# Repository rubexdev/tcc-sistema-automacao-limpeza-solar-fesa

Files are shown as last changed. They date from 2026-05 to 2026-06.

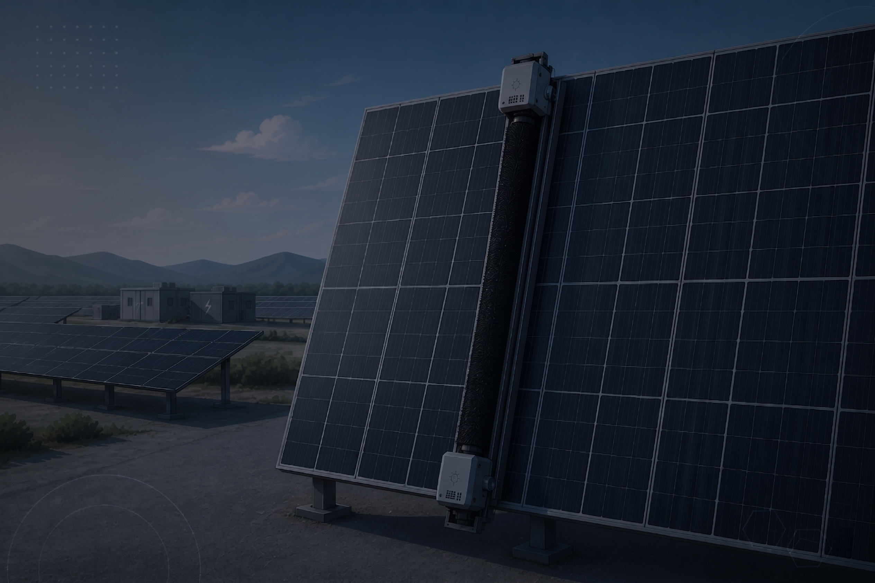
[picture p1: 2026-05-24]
interface-web/Background Interface.png

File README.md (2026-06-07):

# Protótipo de Sistema Automatizado de Limpeza de Placas Solares com Controle Web e Alimentação Autônoma

## 📝 Resumo do Projeto
Este projeto apresenta o desenvolvimento de um protótipo em escala reduzida para limpeza a seco de painéis fotovoltaicos utilizando o microcontrolador ESP32, escova cilíndrica de nylon e monitoramento remoto em tempo real via interface web integrada ao Firebase. 

O mecanismo demonstrou uma **eficiência média global de 94,0% na remoção mecânica de partículas** e validou a restauração da capacidade de geração elétrica através de ensaios comparativos de carregamento.

---

## 📺 Demonstração em Vídeo
▶️ **[Clique aqui para assistir ao vídeo de demonstração do protótipo no Google Drive](https://drive.google.com/file/d/1mZMj68gSKPB6pUv0N98ByAwMNWDLgsBo/view?usp=drive_link)**

---

## 📜 Artigo Científico Final (V-06)
📕 **[Clique aqui para ler o artigo completo em PDF](documentos/Artigo_Limpeza_Paineis_Fotovoltaicos.pdf)**

---

## ⚙️ Principais Recursos e Tecnologias
- **Hardware & Automação:** Microcontrolador ESP32 (WROOM-32), Drivers de acionamento BTS7960, Motores DC de alto torque, Sensores de Tensão e Sensores Ultrassônicos (HC-SR04).
- **Armazenamento & Nuvem:** Google Firebase (Realtime Database para sincronização em tempo real e Firebase Authentication para controle de acesso).
- **Interface Web:** Desenvolvida em HTML, CSS e JavaScript hospedada via GitHub Pages.
- **Engenharia & Modelagem:** Diagramas elétricos desenhados no EPLAN Electric P8 e modelagem mecânica 3D desenvolvida no Autodesk Inventor (conjunto modular de 23,75 kg distribuído em 8 rodas de elastômero).

---

## 📂 Estrutura do Repositório
- `/documentos`: Contém o artigo científico final do TCC em formato PDF.
- `/firmware`: Código-fonte (.ino) desenvolvido para o ESP32.
- `/interface-web`: Arquivos de código do painel de controle web (HTML/CSS/JS).
- `/eletrica`: Esquemas elétricos e diagramas gerados no EPLAN.
- `/mecanica`: Arquivos de modelagem completa (peças e conjuntos) do Autodesk Inventor.

---

## 🛠️ Análise de Engenharia (FMEA)
Foi aplicada a metodologia **FMEA (Failure Mode and Effects Analysis)** para mapear vulnerabilidades do projeto a longo prazo, definindo ações preventivas em software e hardware contra:
- Risco de microabrasões no vidro temperado por partículas rígidas externas.
- Perda de eficiência de varredura por desgaste natural das cerdas de nylon.
- Acúmulo de contaminantes aderidos (oleosidade/umidade).

---

## 🎓 Autores e Filiação Acadêmica

### Integrantes:
* Augusto Araujo Bueno
* Bruno Kayki Ribeiro de Souza
* Gustavo da Paz Coelho
* Itamar Silva de Sousa Júnior
* Rubens Melo de Souza

### Orientador:
* Me. Antônio José do Couto Pitta

### Instituição:
* Faculdade Engenheiro Salvador Arena (FESA)
* Bacharelado em Engenharia de Controle e Automação

---

## 📚 Como Citar este Trabalho (ABNT)

BUENO, A. A.; SOUZA, B. K. R.; COELHO, G. P.; SOUSA JÚNIOR, I. S.; SOUZA, R. M. **Protótipo de sistema automatizado de limpeza de placas solares com controle web e alimentação autônoma**. 2026. Artigo (Graduação em Engenharia de Controle e Automação) - Faculdade Engenheiro Salvador Arena, São Bernardo do Campo, 2026.

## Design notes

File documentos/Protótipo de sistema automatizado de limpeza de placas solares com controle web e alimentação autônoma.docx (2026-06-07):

Protótipo de sistema automatizado de limpeza de placas solares com controle web e alimentação autônoma

Augusto Araujo Bueno, Bruno Kayki Ribeiro de Souza, Gustavo da Paz Coelho, Itamar Silva de Sousa Júnior, Rubens Melo de Souza.¹

Me. Antônio José do Couto Pitta

Resumo

A eficiência de módulos fotovoltaicos é frequentemente reduzida pelo acúmulo de sujidade, exigindo limpezas periódicas para evitar perdas de geração (Araujo et al., 2019; Adekanbi, 2024). Neste contexto, este trabalho apresenta um protótipo automatizado para limpeza a seco de placas solares, com controle web e alimentação autônoma, visando otimizar a manutenção, reduzir custos e preservar a eficiência energética. A metodologia englobou o projeto mecânico no Autodesk Inventor, o elétrico no EPLAN Electric P8 e a interface web no Visual Studio Code, integrada ao Firebase. O hardware baseia-se no módulo ESP32-WROOM-32, motores DC acionados por pontes H (BTS7960), sensores de tensão e ultrassônicos, controlador de carga e escova cilíndrica de nylon. Foram realizados testes experimentais de remoção de partículas e desempenho energético. Os resultados comprovaram 94,0% de eficiência média na limpeza de sujidade simulada, garantindo operação autônoma e monitoramento remoto em tempo real. Embora os testes não tenham registrado aumento expressivo na tensão após a limpeza, o sistema validou sua viabilidade técnica, baixo impacto ambiental e forte potencial para sistemas fotovoltaicos.

Palavras-chave: Sistemas fotovoltaicos. Automação de limpeza. Controle Web. Alimentação Autônoma. Remoção de partículas.

Abstract

The efficiency of photovoltaic modules is frequently reduced by the accumulation of soiling, requiring periodic cleaning to prevent generation losses (Araujo et al., 2019; Adekanbi, 2024). In this context, this work presents an automated prototype for the dry cleaning of solar panels, with web control and autonomous power supply, aiming to optimize maintenance, reduce costs, and preserve energy efficiency. The methodology encompassed the mechanical design in Autodesk Inventor, the electrical design in EPLAN Electric P8, and the web interface in Visual Studio Code, integrated with Firebase. The hardware is based on the ESP32-WROOM-32 module, DC motors driven by H-bridges (BTS7960), voltage and ultrasonic sensors, a charge controller, and a cylindrical nylon brush. Experimental tests were conducted for particle removal and energy performance. The results proved an average efficiency of 83.5% in cleaning simulated soiling, ensuring autonomous operation and real-time remote monitoring. Although the tests did not register a significant increase in output voltage after cleaning, the system validated its technical feasibility, low environmental impact, and strong potential for photovoltaic systems.

Keywords: Photovoltaic systems. Cleaning automation. Web control. Autonomous power supply. Particle removal.

¹ Faculdade Engenheiro Salvador Arena, Centro Educacional da Fundação Salvador Arena, Estrada dos Alvarengas, 4001 - São Bernardo do Campo - SP

1 Introdução

A crescente procura por soluções sustentáveis na geração de eletricidade tem promovido mudanças significativas na matriz energética mundial. Nesse contexto, a energia solar desponta como uma alternativa estratégica, limpa e renovável, capaz de reduzir impactos ambientais e contribuir para a diversificação da matriz (Titara, 2024).

Nos últimos anos, esse movimento também se intensificou no Brasil, onde a energia solar tornou-se a segunda maior fonte elétrica do país, atrás apenas das hidrelétricas. O aumento da demanda, aliado a incentivos e ao avanço tecnológico, tem ampliado o acesso da população a essa modalidade (Costa, 2024). Em 2024, o país possuía aproximadamente 43 GW de potência instalada, e em 2025 atingiu a marca de 60 GW, passando a representar mais de 23% de toda a potência elétrica nacional (Absolar, 2025). Esse avanço trouxe impactos importantes, como a redução das emissões de CO₂, a geração de empregos e a captação de investimentos em diferentes regiões (Casarin, 2025).

No entanto a consolidação da energia solar também evidencia desafios técnicos relacionados à operação e manutenção dos sistemas instalados. A eficiência e o rendimento dos módulos fotovoltaicos estão diretamente condicionados à manutenção preventiva, em especial à limpeza das superfícies. A exposição contínua ao ambiente favorece o acúmulo de poeira, partículas provenientes da poluição atmosférica, folhas e outros resíduos, que atuam como barreiras à incidência da radiação solar sobre as células fotovoltaicas, comprometendo significativamente seu desempenho (Araujo et al., 2019). De acordo com Adekanbi (2024), “[...] as perdas anuais de energia devido ao soiling podem variar entre 3% e 5% em regiões de clima moderado, mas ultrapassam 30% em áreas áridas ou altamente poluídas.”. Esse fator assume particular relevância no Brasil, sobretudo em centros urbanos, onde o crescimento progressivo dos índices de poluição intensifica a deposição de partículas sobre os módulos e acelera a queda de eficiência (Lima; Souza, 2025).

A metodologia de limpeza convencional, predominantemente manual, apresenta limitações importantes. Entre os principais entraves destacam-se o acesso restrito a estruturas instaladas em telhados ou locais elevados, a dependência de mão de obra especializada, o custo elevado das operações periódicas e o risco de danos aos módulos quando a limpeza é realizada de forma inadequada (Mondal et al., 2018). Além disso, a realização esporádica dessas manutenções não acompanha o ritmo do acúmulo de sujeira, resultando em períodos prolongados de operação dos módulos em condições subótimas, uma vez que a presença de partículas como poeira, poluição e detritos reduz a eficiência e a capacidade de geração de energia dos sistemas fotovoltaicos (Sousa, Neto, 2024).

Diante desse cenário, a automação da limpeza se apresenta como uma alternativa promissora. A integração de microcontroladores a uma interface web supervisória possibilita o monitoramento remoto e o acionamento automático do sistema de limpeza, reduzindo a necessidade de intervenção manual e aumentando a confiabilidade da geração (Mello et al., 2003). O diferencial está na proposta de desenvolver uma solução de baixo custo com potencial de escalabilidade para diferentes tipos de empreendimentos de maior dimensão, como sistemas fotovoltaicos residenciais e usinas solares. Essa característica amplia a viabilidade da tecnologia e fortalece o papel da energia solar como componente essencial da transição energética sustentável (Lacerda; Canel; Lopes, 2022).

Nesse contexto, o objetivo geral do projeto se dá no desenvolvimento de um sistema de limpeza automatizado para placas fotovoltaicas utilizando controle web e alimentação autônoma, de modo a maximizar a eficiência energética e reduzir os custos de manutenção. Dessa forma, devem ser cumpridos os seguintes objetivos específicos:

a) Projetar a estrutura mecânica da plataforma de limpeza adequada para os módulos fotovoltaicos, garantindo cobertura completa e eficiência operacional;
b) Desenvolver alternativa elétrica para o sistema que seja alimentado pelo painel solar;
c) Desenvolver a lógica de controle do microcontrolador para a automação da limpeza e implementar a interface web supervisória para acionamento remoto e monitoramento das variáveis do sistema;
d) Projetar o mecanismo de limpeza garantindo contato tangencial com a superfície do painel fotovoltaico e livre deslizamento ao longo de seu comprimento, visando a adaptabilidade do sistema a instalações com maior quantidade de painéis;
e) Avaliar a eficiência energética dos módulos antes e depois da limpeza automatizada, visando atingir um resultado de 85% de limpeza.
2 Referencial teórico

Inicialmente, serão apresentados trabalhos acadêmicos que estudam o impacto do acúmulo de sujidade na eficiência de sistemas fotovoltaicos, bem como experiências com sistemas automatizados de limpeza de painéis e a validação de sua efetividade, fornecendo suporte conceitual e técnico para o desenvolvimento do sistema proposto.

  2.1 Impacto da sujidade sobre o desempenho de sistemas fotovoltaicos

O estudo realizado por Júnior, Cruz e Amaral (2018) analisou os efeitos do acúmulo de sujeira sobre as placas de um sistema fotovoltaico real, quantificando a redução provocada na geração de energia. Segundo Lemos et al. (2016), o impacto da sujidade pode ocasionar reduções de desempenho entre 4% e 26,3%, variando conforme o tipo de célula, as características da poeira e as condições climáticas locais. Fatores como a rugosidade da superfície dos módulos, sua inclinação, a velocidade dos ventos e a frequência de chuvas são igualmente determinantes no acúmulo de sujeira (Maghami et al., 2016; Mani; Pillai, 2010).

A sujidade é definida como o acúmulo de resíduos inorgânicos na superfície dos módulos, como poeira, pólen, carbono amorfo proveniente da queima de combustíveis e resíduos oleosos oriundos de processos produtivos e tráfego de veículos (Lemos, 2016). Como a geração elétrica depende da incidência de fótons na superfície dos módulos, qualquer barreira física reduz a absorção de energia e compromete a produção (Duarte et al., 2015). De acordo com Villalva (2015), a eficiência das células fotovoltaicas varia geralmente entre 14% e 20%, dependendo da tecnologia utilizada, tornando qualquer redução por sujidade um fator relevante para o desempenho do sistema.

Júnior, Cruz e Amaral (2018) constataram que os índices de geração decaem em média 20% em decorrência do acúmulo de sujidade, estabelecendo um intervalo mínimo de periodicidade de limpeza dos módulos. O trabalho evidenciou ainda que, em períodos de chuvas frequentes, a limpeza natural permite reduzir substancialmente ou eliminar a necessidade de limpeza manual das placas.

  2.2 Automatização da manutenção de placas solares

Sousa e Neto (2024) propõem o uso da automação como solução para reduzir custos operacionais na manutenção de módulos fotovoltaicos, destacando que o acúmulo de sujeira pode provocar perdas de até 25% na geração de energia, além de causar danos às células devido ao aquecimento desigual e à formação de fissuras.

No estudo de Vieira Júnior (apud Sousa; Neto, 2024), a coleta de dados realizada cinco meses antes e cinco meses após a limpeza dos módulos revelou um aumento de 12,08% na geração logo após a limpeza, com decréscimo progressivo de até 7,56% ao longo dos meses seguintes, confirmando a necessidade de limpezas periódicas.

Com base nesses resultados, Sousa e Neto (2024) propõem um sistema automatizado composto por sensores de sujidade, sistema de ativação automática por relés e atuadores, bomba de água e controlador (Arduino ou CLP), concluindo que a automação da manutenção representa uma estratégia eficaz para conciliar eficiência energética e viabilidade econômica.

  2.3 Sistema sustentável e automatizado para limpeza de placa solares em residências

O trabalho apresentado por Lima, Jesus e Souza (2024) descreve o desenvolvimento do projeto Clear Sun, um sistema automatizado de limpeza de placas solares voltado a residências e telhados de difícil acesso, com o objetivo de maximizar a captação de energia e reduzir custos operacionais com manutenção manual. O sistema propõe a utilização de um escovão posicionado transversalmente à placa, movimentado por um motor DC para rotação e deslocado ao longo da superfície por um motor de passo controlado por Arduino Nano e ESP32, com uso de bomba de água para a limpeza úmida — desligada automaticamente por um sensor de chuva quando umidade é detectada nas placas.

Os autores destacam que muitos usuários não realizam a limpeza necessária dos painéis, sendo que em alguns casos a higienização ocorre apenas de dois a três anos após a instalação, comprometendo significativamente a eficiência energética do sistema. Embora o projeto represente um avanço na automação da manutenção, a dependência de recursos hídricos pode ser uma limitação em regiões com escassez de água ou sem acesso fácil a reservatórios, aspecto contornado pelo sistema proposto no presente trabalho, que adota limpeza a seco.

  2.4 Limpador automático de painéis solares baseado em IoT em edifícios no Egito

Um estudo desenvolvido por Anber e Aboshosha (2024) investigou o uso de um limpador automático de painéis solares baseado em IoT no Egito, em região de clima desértico. O objetivo do trabalho foi mensurar a influência da poeira sobre os módulos fotovoltaicos e verificar a efetividade da limpeza automatizada. Os autores constataram que a eficiência dos painéis, reduzida em até 89,33% devido ao acúmulo de poeira, pôde ser restaurada para 99,4% de sua potência original por meio do sistema automatizado, demonstrando a relevância da automação na manutenção de painéis solares.

A literatura indica que a automação da limpeza, quando aliada ao monitoramento em tempo real por meio de IoT, constitui uma estratégia tecnológica eficaz para mitigar essas perdas. Nesse sentido, a figura 1 apresenta a proposta deste trabalho, que utiliza uma interface IoT, por meio de um celular, para controle de um eixo horizontal de limpeza (Anber; Aboshosha; 2024).

Os testes experimentais demonstraram que a aplicação do sistema de limpeza automática baseado em IoT foi capaz de recuperar a eficiência dos painéis para cerca de 99,5% do valor original, evidenciando a alta eficácia do método na remoção de sujeira e na restauração da capacidade de geração de energia (Anber; Aboshosha; 2024).

Figura 1 – Limpador automático de painéis solares baseado em IoT com monitoramento remoto

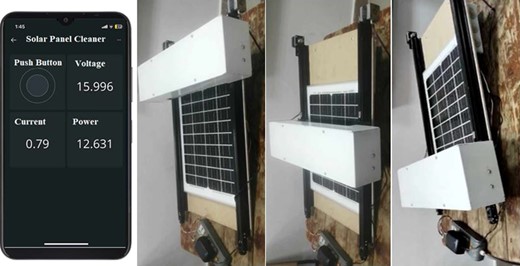
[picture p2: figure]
The proposed IoT-controlled solar panel cleaner system, (a) the dashboard app, (b) the brush at rest (home position), (c) the brush at the middle of the panel during the cleaning process, and (d) the brush at the end of the forward motion and the start to the reverse motion.

Fonte: Anber e Aboshosha (2024).

  2.5 Robô limpador de painel solar

O trabalho apresentado por Maciel et al. (2023) descreve o desenvolvimento de um robô limpador de painéis fotovoltaicos, conforme ilustrado na figura 2, com o objetivo de otimizar a eficiência na geração de energia por meio de limpeza periódica e semiautomatizada. A principal inovação do protótipo é a adoção de limpeza a seco, dispensando o uso de água ou produtos químicos, o que reduz o impacto ambiental e preserva a integridade das placas.

Figura 2 – Robô limpador para limpeza a seco de placas

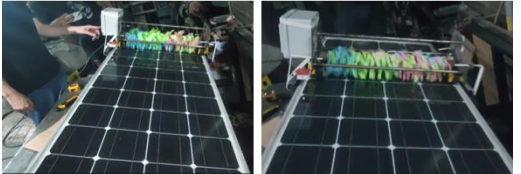
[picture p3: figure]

Fonte: Maciel et al. (2023).

O robô utiliza escovas de microfibra rotativas para remover poeira e partículas que podem reduzir em até 30% a eficiência dos módulos solares, mantendo a superfície sem riscos de danos como “hot spots”. Sua estrutura em ferro garante robustez, enquanto o controle por Arduino Uno gerencia os motores de corrente contínua e os sensores ultrassônicos, assegurando a movimentação segura e os ciclos de limpeza (Maciel et al., 2023).

Os testes de eficiência foram conduzidos com farinha de trigo como sujeira simulada, distribuída em quatro etapas de 250 g cada sobre a superfície da placa. Ao final dos ciclos de limpeza, os autores constataram uma eficiência média de 83,3% na remoção da sujeira simulada, confirmando a viabilidade prática do protótipo. A análise financeira realizada pelos autores indicou ainda que a falta de limpeza periódica pode resultar em perdas anuais significativas, reforçando o retorno econômico de soluções automatizadas de manutenção (Maciel et al., 2023).

3 Metodologia

Para o desenvolvimento do protótipo do sistema de limpeza automatizado, foram realizadas as seguintes etapas: estudo do método de limpeza, desenvolvimento dos projetos mecânico e elétrico, definição da lógica de funcionamento e programação de controle, implementação do método de comunicação entre o microcontrolador e as interfaces, desenvolvimento da interface web e da interface física local e, por fim, validação do sistema por meio de testes de funcionamento.

O protótipo é composto pelos seguintes componentes principais: um microcontrolador ESP32, três drivers de acionamento de motores BTS7960, dois motores DC de alto torque 5840-555 de 24 V, um motor DC RS555 de 12 V, dois sensores de tensão, dois sensores ultrassônicos, um display LCD 20x4 com comunicação I2C, dois botões, um controlador de carga solar, duas baterias de 12 V e uma escova de limpeza cilíndrica. O diagrama funcional, apresentado na figura 3, ilustra a arquitetura do sistema e a interação entre seus componentes.

Figura 3 – Diagrama funcional: arquitetura e interação entre subsistemas

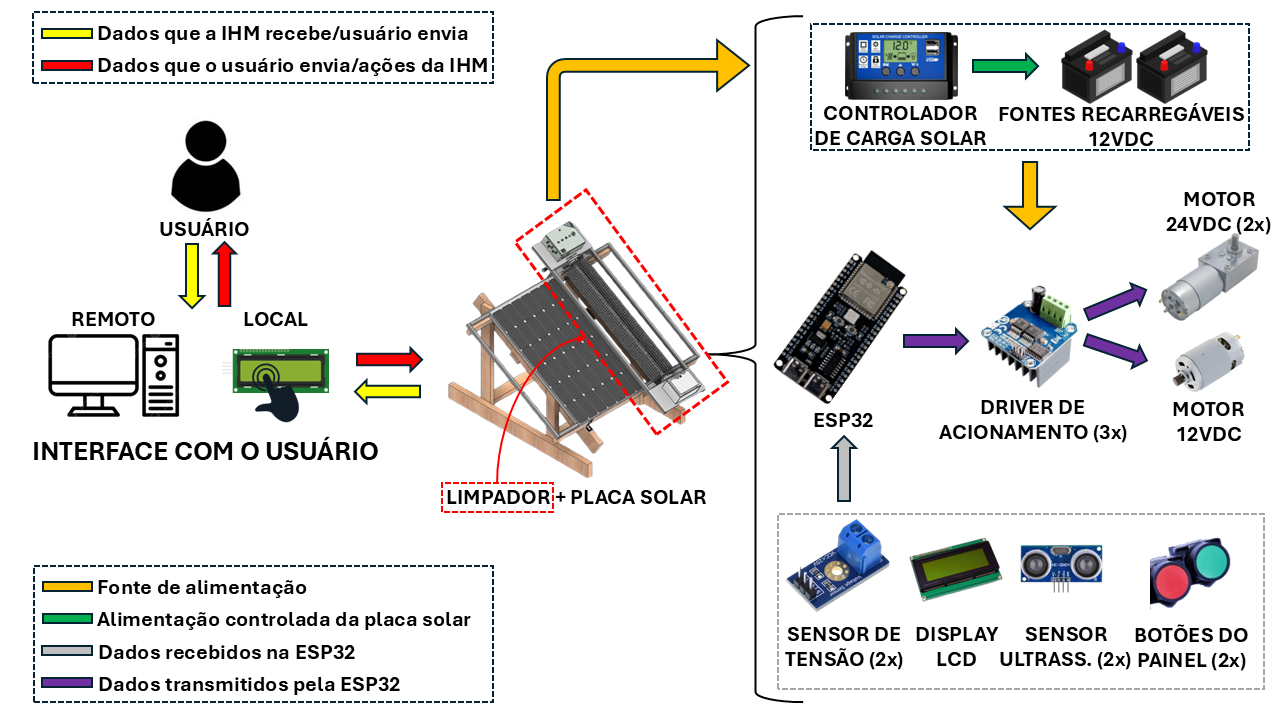
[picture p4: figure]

Fonte: Autoria Própria (2026).

Cabe destacar que o protótipo não foi desenvolvido sobre um painel fotovoltaico de dimensão padrão, uma vez que a aquisição de componentes em escala real excederia os recursos disponíveis. Optou-se, portanto, pela construção em escala reduzida, utilizando uma placa fotovoltaica com dimensões aproximadas de 1135 × 730 × 35 mm, composta por 36 células. Para a realização dos testes, foi desenvolvida uma estrutura de apoio em madeira, responsável por sustentar a placa fotovoltaica e, consequentemente, o limpador, que opera sob a superfície da placa. Essa abordagem permite demonstrar o funcionamento do sistema proposto e validar os princípios de automação aplicados ao mecanismo de limpeza.

O sistema de limpeza pode ser acionado de forma manual, por meio do painel de controle ou das interfaces desenvolvidas, ou de forma automática, mediante a definição de um intervalo de tempo para a periodicidade da limpeza. Os comandos são enviados à ESP32, responsável pelo processamento da lógica de controle e pelo acionamento dos drivers e motores. O monitoramento da posição do limpador é realizado por dois sensores ultrassônicos HC-SR04.

A alimentação do sistema é provida por duas baterias de 12 V, cuja tensão é distribuída e convertida para diferentes níveis ao longo do circuito: um conversor elevador fornece 24 V para os motores de deslocamento do limpador (modelo 5840-555), enquanto os 12 V nativos alimentam o motor da escova cilíndrica (modelo RS555) e um conversor abaixador fornece 5 V para a lógica de controle. O acionamento e reversão de todos os motores são controlados por pontes H BTS7960. As baterias são recarregadas por um controlador de carga alimentado pelo próprio painel fotovoltaico, aproveitando a energia gerada pelo sistema para sua autonomia operacional.

Para o monitoramento da alimentação do sistema, proveniente das baterias, utilizam-se dois sensores de tensão, cujos dados são enviados à ESP32, permitindo uma análise indireta do desempenho do painel fotovoltaico.

  3.1 Método de limpeza e material da escova

Com base nos referenciais teóricos estudados, o método adotado pelo sistema de limpeza automatizado desenvolvido é a limpeza a seco, realizada por meio de um eixo rotativo acoplado a uma escova cilíndrica que percorre a superfície do painel por contato mecânico, conforme ilustrado na figura 4. O princípio de funcionamento consiste na rotação da escova em alta velocidade, promovendo a remoção de partículas depositadas sobre a superfície por meio de contato mecânico controlado. A geometria cilíndrica permite uma distribuição uniforme das forças de contato ao longo da área de limpeza, garantindo maior eficiência na remoção da sujeira sem concentrar esforços excessivos em pontos específicos.

Figura 4 – Método de limpeza a seco proposto para o sistema de limpeza automatizado

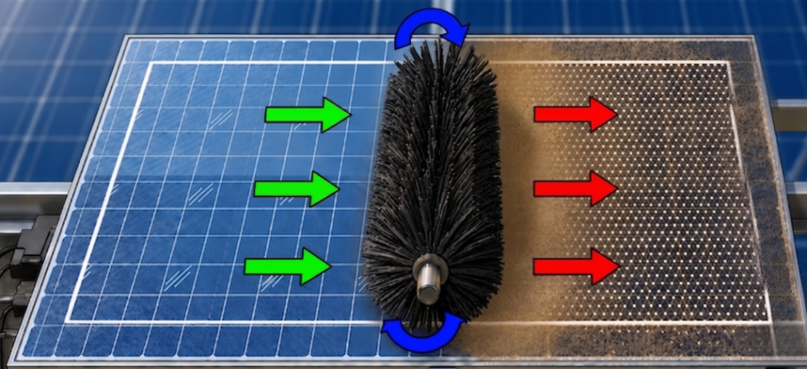
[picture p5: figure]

Fonte: Autoria Própria (2026).

A adoção do sistema de limpeza a seco justifica-se por aspectos técnicos, ambientais e operacionais. Esse método elimina o consumo hídrico, fator crucial para regiões que enfrentam escassez de água. Além disso, evita a formação de resíduos minerais provenientes da evaporação, os quais podem comprometer o desempenho dos módulos. Outro benefício relevante é a mitigação de riscos elétricos durante a operação, pois a ausência de água dispensa a necessidade de desligamento do sistema, garantindo maior continuidade na geração de energia. Por fim, a eliminação de componentes hidráulicos simplifica a estrutura do sistema, reduzindo os custos operacionais e facilitando sua aplicação em ambientes remotos e com soluções automatizadas.

Tomando como referência o painel fotovoltaico de 36 células, o dimensionamento da escova foi realizado por meio de projeto sob medida no software Autodesk Inventor, resultando nas seguintes especificações: diâmetro externo de 200 mm, comprimento de 1100 mm, furo central de 25 mm para acoplamento ao eixo e base estrutural de 75 mm, com cerdas de nylon preto com espessura entre 0,20 mm e 0,30 mm, conforme ilustrado na figura 5(a). A figura 5(b) apresenta a escova fabricada conforme o projeto, composta por cerdas de nylon preto e reforçada para uso contínuo.

Figura 5 – Vista isométrica da escova em 3D 5(a) e perspectiva frontal da escova fabricada 5(b)

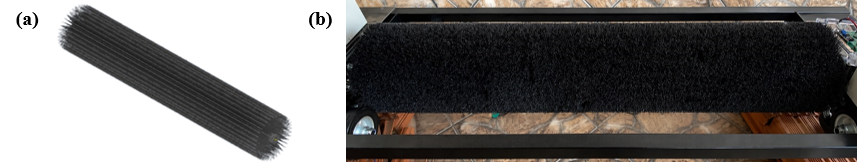
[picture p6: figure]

Fonte: Autoria Própria (2026).

A escolha do nylon como material das cerdas contribui para a preservação da integridade do vidro do módulo fotovoltaico, uma vez que apresenta dureza inferior à do vidro, reduzindo o risco de microabrasões. Esse fator é fundamental para manter a eficiência energética do sistema ao longo do tempo, evitando perdas associadas a danos superficiais.

Dessa forma, o método de limpeza adotado estabelece as bases para o desenvolvimento estrutural do sistema uma vez que as características geométricas e operacionais da escova influenciam diretamente na concepção mecânica do conjunto. Assim, torna-se necessária a modelagem do limpador horizontal, considerando aspectos como dimensões, distribuição de massa, pontos de fixação e integração dos componentes responsáveis pelo deslocamento e acionamento do sistema.

  3.2 Modelagem mecânica

Após a definição do método de limpeza e do material da escova, o projeto mecânico foi modelado no software Autodesk Inventor com base nos componentes adquiridos para o protótipo. Foram definidos os principais elementos estruturais do limpador, como suportes de fixação, eixo de movimento, base dos motores e proteções, sendo cada peça modelada individualmente e posteriormente integrados ao conjunto. A figura 6(a) apresenta a vista explodida do projeto mecânico em 3D, enquanto a figura 6(b) mostra a lista de componentes e suas respectivas massas, resultando em um peso total aproximado do conjunto de 23,75 kg.

Figura 6 – Montagem em 3D completa 6(a) e lista de peças 6(b)

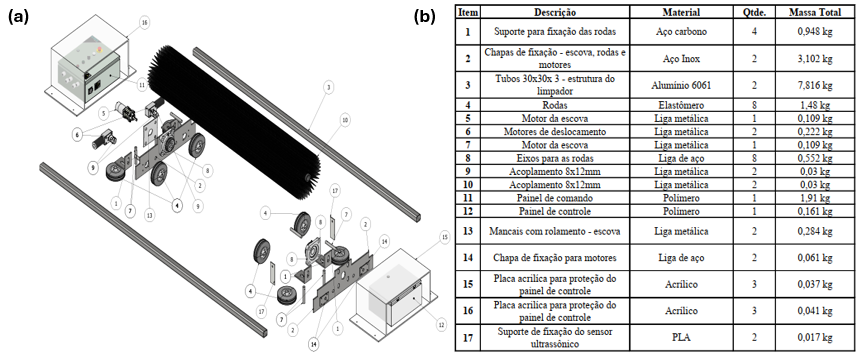
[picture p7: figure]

Fonte: Autoria Própria (2026).

A estrutura do limpador é composta por perfis de alumínio e chapas de aço soldadas, que integram os suportes das rodas, a base dos motores e o alojamento dos painéis de comando, formando um conjunto rígido e funcional. A Figura 7(a) apresenta a vista isométrica do projeto tridimensional, enquanto a Figura 7(b) ilustra o limpador horizontal construído.

Figura 7 – Vista isométrica em 3D 7(a) e perspectiva frontal do protótipo montado 7(b)

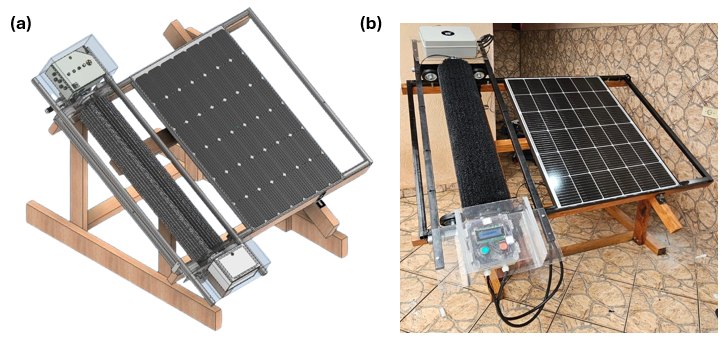
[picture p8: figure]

Fonte: Autoria Própria (2026).

O projeto foi concebido com base no princípio da modularidade: o limpador é sobreposto ao painel fotovoltaico, sem fixação permanente, permitindo sua remoção e reinstalação em outros conjuntos de placas, o que amplia a aplicabilidade do sistema e reduz custos de implantação. Essa concepção modular, aliada às características geométricas e à massa total do conjunto, determinou as demandas operacionais envolvidas no deslocamento e acionamento do sistema, influenciando diretamente o dimensionamento elétrico e a arquitetura do sistema de controle.

Dessa forma, faz-se necessário o desenvolvimento de um painel elétrico capaz de integrar os motores, sensores e dispositivos de proteção, garantindo o funcionamento seguro e automatizado do sistema.

  3.3 Circuito elétrico

O projeto elétrico foi desenvolvido no software EPLAN Electric P8, ferramenta de engenharia que facilita a visualização das ligações e a montagem do circuito. O diagrama elétrico pode ser observado na figura 8.

Figura 8 – Diagrama elétrico do projeto

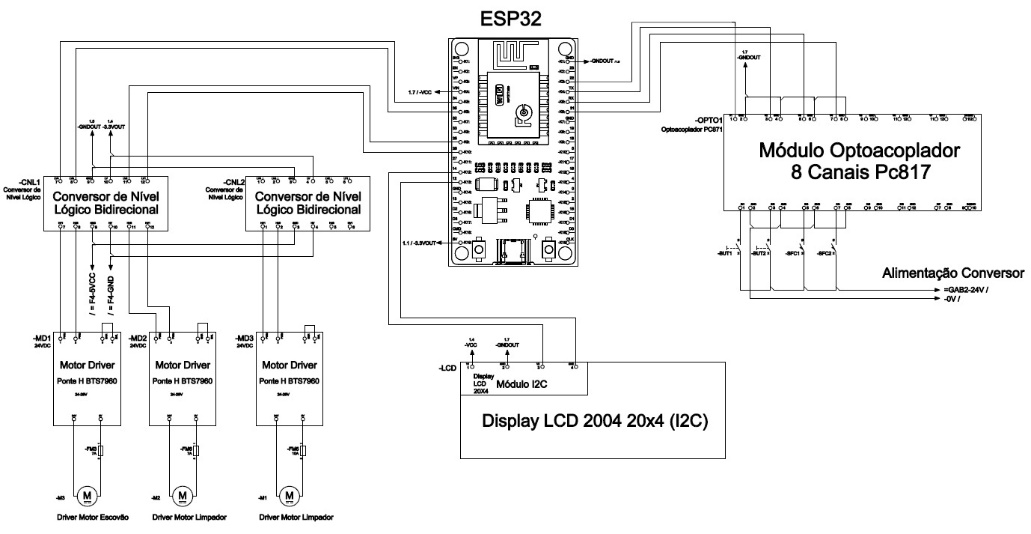
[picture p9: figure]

Fonte: Autoria Própria (2026).

Dado que o sistema integra componentes de acionamento de alta tensão e componentes de controle mais sensíveis, optou-se pela separação em dois painéis distintos: o painel de comando, destinado aos componentes de acionamento e maior tensão, e o painel de controle, de menor porte, responsável por abrigar os componentes eletrônicos mais sensíveis.

O painel de comando, apresentado na figura 9, abriga os seguintes componentes: controlador de carga solar (A), responsável pela gestão de corrente e tensão do circuito; disjuntor bipolar (B), para proteção exclusiva do controlador de carga; conversor elevador de tensão (C), responsável pela conversão de 12 V para 24 V; e três drivers BTS7960 (D), sendo dois destinados aos motores de deslocamento e um ao motor de rotação da escova. O painel conta ainda com prensas-cabo (E), para entrada e saída de cabos, e uma ventoinha (F), para dissipação do calor gerado pelos componentes em operação.

Figura 9 – Vista interna dos componentes do Painel de Controle.

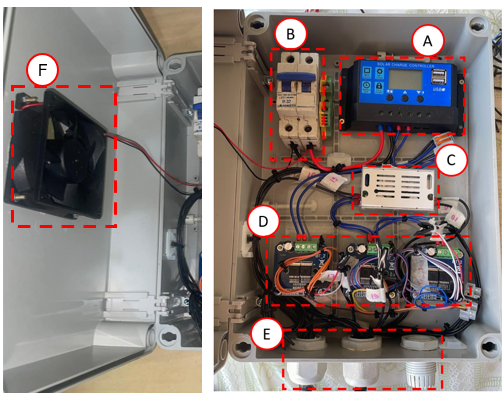
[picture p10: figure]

Fonte: Autoria Própria (2026).

O painel de controle, apresentado nas Figuras 10(a) e 10(b), abriga os seguintes componentes: controlador ESP32 (A), microcontrolador central responsável pela lógica e controle do sistema; módulo optoacoplador de 8 canais (B), utilizado para leitura dos botões de 24 V, protegendo a ESP32 contra sinais de tensão incompatíveis; conversores de nível bidirecional (C) e sensores de tensão (D), soldados em placa de soldagem, sendo os primeiros responsáveis pela elevação do sinal de 3,3 V para 5 V para acionamento das pontes H, e os segundos pelo monitoramento da tensão das baterias; conversor abaixador de tensão (E), que converte 24 V para 5 V para alimentação da lógica de controle; display LCD (F), utilizado como interface visual local; botões de 24 V verde (G) e vermelho (H), para acionamentos manuais e interação com o display; e prensas-cabo (I), para entrada e saída de cabos.

Figura 10 – Disposição interna do painel de controle 10(a) e disposição externa do painel de controle 10(b).

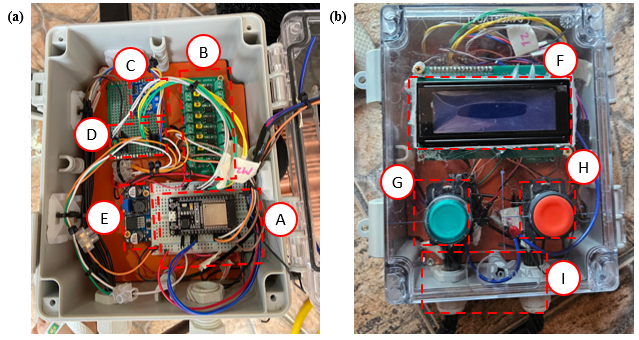
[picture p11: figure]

Fonte: Autoria Própria (2026).

A alimentação do sistema ocorre por meio de duas baterias de 12 V, mantidas carregadas por um ciclo de autonomia energética provido pela própria placa fotovoltaica do protótipo, conforme ilustrado na figura 11. O ciclo se inicia com a geração de energia pelo painel fotovoltaico, que fornece tensão de aproximadamente 24 V e corrente nominal de até 7,55 A. Essa energia é gerida pelo controlador de carga solar, responsável por regular a tensão e a corrente de entrada, garantindo o carregamento seguro das baterias. Uma vez carregadas, as baterias fornecem alimentação ao sistema de controle e acionamento, que por sua vez comanda o limpador durante os ciclos de limpeza. Concluída a operação, o sistema retorna ao estado de monitoramento, aguardando o próximo ciclo programado, enquanto o painel fotovoltaico continua recarregando as baterias.

Figura 11 – Ciclo da alimentação autônoma do protótipo.

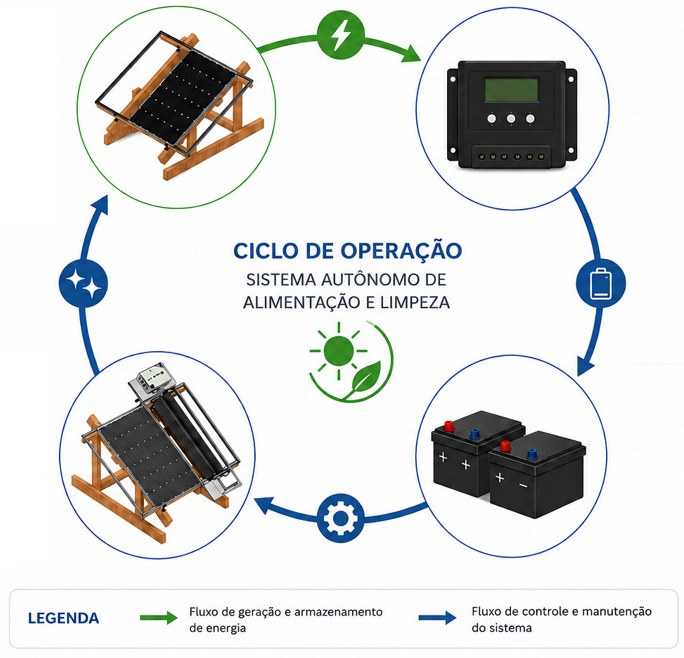
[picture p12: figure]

Fonte: Autoria Própria (2026).

  3.4 Lógica de funcionamento

O sistema de limpeza foi concebido com base em uma estratégia de operação por intervalos de tempo configuráveis pelo usuário. Nessa abordagem, o operador define os períodos ao longo do dia em que a limpeza deve ser executada, e o sistema realiza automaticamente dois ciclos completos a cada intervalo programado. Cada ciclo consiste em uma passagem de ida e uma passagem de volta do limpador ao longo da superfície do painel fotovoltaico. A repetição consecutiva das passagens tem por objetivo maximizar a remoção de partículas e resíduos, compensando a ausência de um sensor de feedback que ateste diretamente o grau de limpeza atingido.

A execução de cada ciclo é controlada pelo acionamento coordenado dos três motores DC e monitorada pelos sensores ultrassônicos dispostos nas extremidades do percurso. A atuação sequencial desses sensores indica a conclusão de cada passagem, comandando a inversão do movimento ou a interrupção do ciclo conforme a etapa em execução. A sequência lógica completa desse processo é ilustrada pelo fluxograma da figura 12.

Figura 12 – Fluxograma do processo

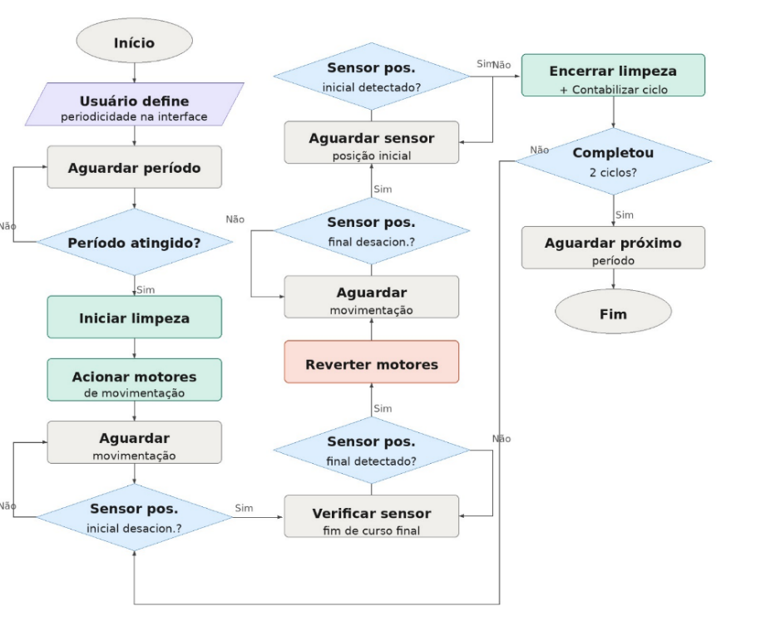
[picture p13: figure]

Fonte: Autoria Própria (2026).

Além do modo automático descrito e apresentado no fluxograma, o sistema oferece um modo manual de operação, no qual o usuário pode acionar a limpeza a qualquer momento por meio da interface web ou da interface física local, independentemente dos intervalos programados. Essa dualidade de controle busca garantir flexibilidade operacional e assegura a continuidade do funcionamento mesmo em situações em que o agendamento automático não seja suficiente ou adequado.

O firmware do sistema foi desenvolvido no Arduino IDE com o framework Arduino para ESP32. A escolha da ESP se justifica pela conectividade Wi-Fi nativa, que viabiliza a integração com serviços em nuvem e o controle remoto dos periféricos, aspectos fundamentais para a proposta de controle web adotada no projeto.

  3.5 Comunicação

Como solução de comunicação entre o microcontrolador e as interfaces de controle, foi adotado o Firebase, plataforma de desenvolvimento em nuvem oferecida pela Google. A plataforma oferece três recursos que potencializam o projeto: (i) hospedagem de dados em nuvem sem necessidade de servidor próprio, de modo que qualquer dispositivo conectado à internet acessa os dados da ESP32 diretamente; (ii) sincronização em tempo real por meio do Realtime Database, um banco de dados NoSQL que atualiza simultaneamente todos os clientes conectados, aspecto especialmente relevante dado que o sistema conta com interface web e interface física operando em paralelo; e (iii) o Firebase Authentication, que restringe o acesso às informações apenas a usuários previamente cadastrados na plataforma.

No banco de dados, todas as variáveis de monitoramento e controle remoto estão organizadas em um único nó estruturado, contemplando: comandos manuais, modo de operação (manual/automático), status dos motores e sentido de rotação (inferido pelo acionamento dos bits da ponte H), status de comunicação com a ESP32, periodicidade configurada para os ciclos de limpeza, contagem de ciclos realizados e tensão individual das duas baterias. Cada variável possui valores predefinidos na estrutura do banco, tratados e selecionados internamente pela programação da ESP32, conforme ilustrado na figura 13.

Figura 13 – Variáveis de tratativa remota no Firebase

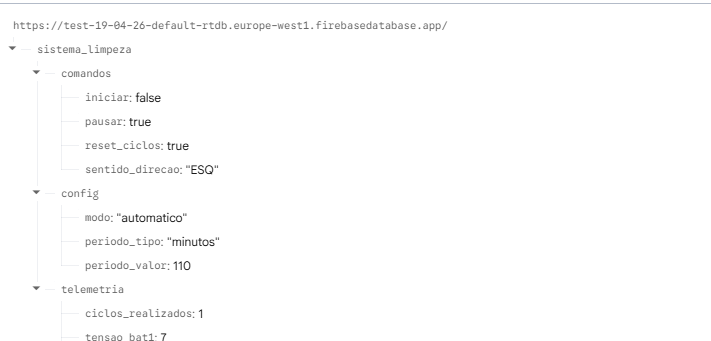
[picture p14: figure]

Fonte: Autoria Própria (2026).

A comunicação entre a ESP32, o Firebase e a Interface Web são estabelecidos por meio de três chaves de configuração únicas por projeto: o apiKey, que identifica a aplicação na plataforma; o authDomain, responsável pelo gerenciamento do fluxo de autenticação; e a databaseURL, que aponta para o banco de dados onde estão armazenadas todas as variáveis do sistema.

  3.6 Interface web

A interface web tem como objetivo permitir o monitoramento e controle remoto do sistema por qualquer dispositivo conectado à internet. Foi desenvolvida em HTML, CSS e JavaScript no Visual Studio Code, com hospedagem no GitHub Pages, o qual disponibiliza o sistema por meio de um link de acesso público com integração direta ao Firebase.

A versão final é composta por duas telas principais. A primeira corresponde ao login, apresentada na figura 14, que restringe o acesso a usuários cadastrados no Firebase Authentication e exibe o status de conexão da ESP32. Após a autenticação, o usuário é direcionado à tela operacional, detalhada na figura 15.

Figura 14 – Tela inicial da interface web

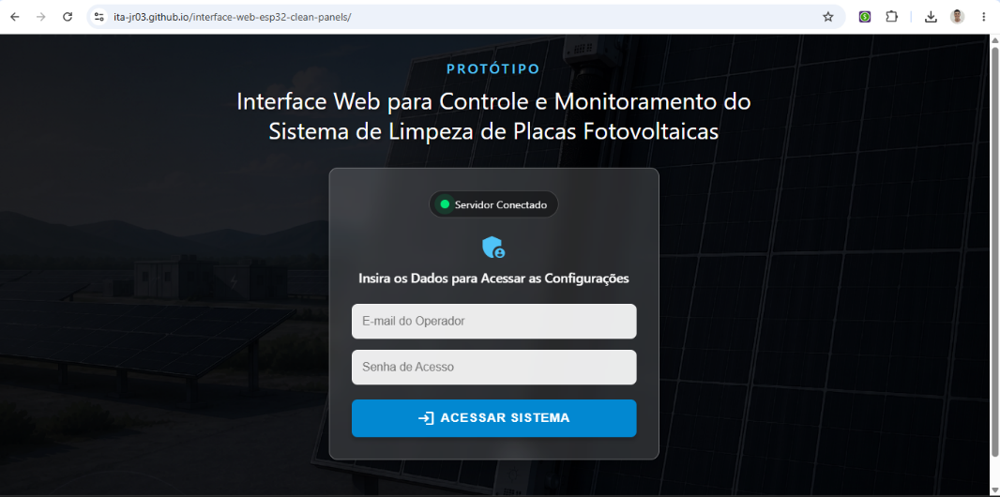
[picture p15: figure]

Fonte: Autoria Própria (2026).

Figura 15 – Tela operacional da interface web

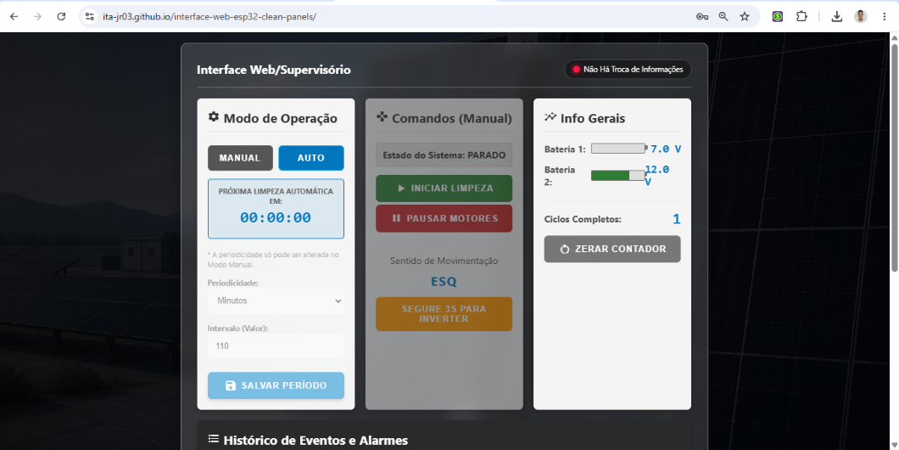
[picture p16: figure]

Fonte: Autoria Própria (2026).

A tela operacional atua como o ambiente principal da interface, funcionando como um sistema supervisório completo. A partir dela, o operador pode alternar entre os modos de operação (manual e automático), enviar comandos de acionamento (restritos ao modo manual) e ajustar a periodicidade das rotinas, definindo a unidade de tempo (minutos, horas ou dias) e o valor numérico do período. A interface também exibe dados gerais de telemetria, como a tensão das baterias de alimentação do circuito e a contagem de ciclos realizados.

Por fim, o sistema conta com uma aba dedicada ao diagnóstico e segurança da aplicação, conforme ilustra a figura 16. Nesta área, o usuário pode visualizar o histórico de alarmes e eventos do sistema, além de realizar o cadastro de novos operadores, com atualização e validação direta no banco de dados do Firebase.

Figura 16 – Histórico de alarmes, eventos e cadastro de usuários

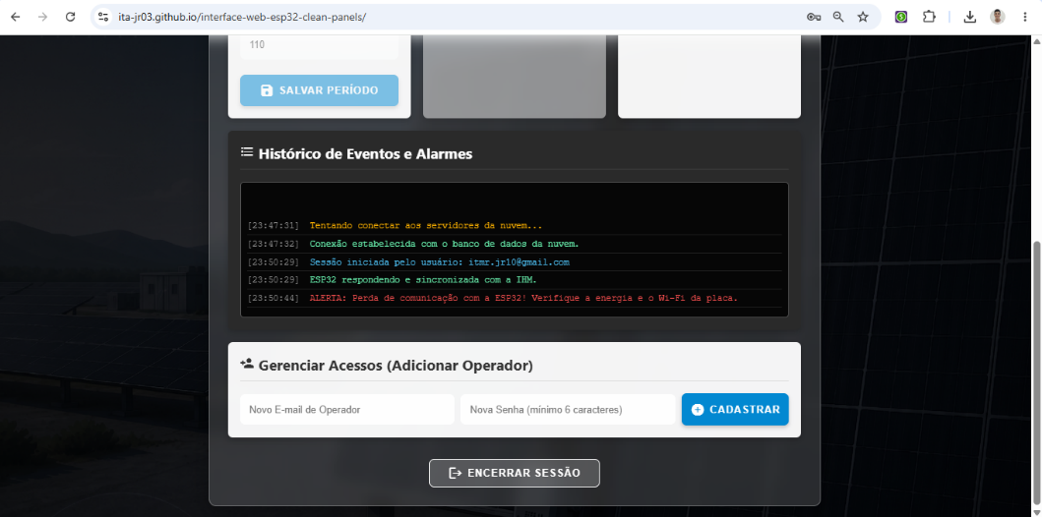
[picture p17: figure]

Fonte: Autoria Própria (2026).

Maiores detalhes do projeto podem ser encontrados no repositório do Github¹.

  3.7 Interface local

O objetivo de implementar uma interface física é proporcionar uma redundância no controle do sistema, assegurando a continuidade da operação mesmo em um eventual cenário de falha de conexão com a internet ou indisponibilidade da interface web.

A interface local está disposta no painel de controle e é composta por um display LCD 20x4, equipado com módulo de comunicação I2C, e dois botões de comando (um verde, para acionamento, e um vermelho, para pausa). Essa configuração oferece acesso e controle direto ao sistema de forma totalmente offline. O display atua de forma complementar, exibindo informações cruciais também presentes na interface web, como: modo de operação (manual ou automático), status de operação do sistema, tensão das baterias e contagem de ciclos realizados.

O acesso ao modo de configuração pelo display é realizado por meio de uma combinação dos comandos físicos: ao pressionar os dois botões simultaneamente por cinco segundos, o sistema entra no menu de parâmetros. Nesse modo, as funções originais dos botões são reatribuídas. O botão verde assume a função de incremento de valores e navegação para a esquerda, enquanto o botão vermelho passa a decrementar valores e navegar para a direita. Após os ajustes, a confirmação das configurações inseridas é feita pressionando novamente ambos os botões de forma simultânea por dois segundos.

  3.8 Custos do protótipo

A viabilidade do projeto envolveu o levantamento dos custos de fabricação do protótipo, categorizados por área de desenvolvimento. A tabela 1 detalha os componentes mecânicos utilizados para a montagem do limpador horizontal, os quais garantem a sustentação da escova, movimentação do equipamento e abriga os componentes de controle do sistema. Cabe ressaltar que determinados materiais foram fornecidos pela Faculdade Engenheiro Salvador Arena (FESA) e, portanto, estão indicados com um asterisco (*) na coluna de preço total das tabelas a seguir.

¹ Todas as documentações sobre o projeto, como projeto mecânico, circuito elétrico e programação, estão disponíveis em: https://github.com/rubexdev/tcc-sistema-automacao-limpeza-solar-fesa

Tabela 1 – Custos da estrutura mecânica do protótipo

Material | Qtde. | Preço Total
Acoplamento 8x12mm – motores | 2 | R$96,00
Chapa de fixação do motor da escova | | *
Chapa de fixação dos motores de deslocamento | | *
Chapa de fixação – suporte do limpador | 2 | *
Escova de limpeza | 1 | R$680,00
Eixo para as rodas | 8 | *
Mancal com rolamento | 2 | R$61,83
Motor de deslocamento | 2 | R$513,00
Motor da escova | 1 | R$360,00
Painel de controle | 1 | R$78,90
Painel de comando | 1 | R$72,59
Placa acrílica para o painel de comando | 1 | *
Rodas 4" | 8 | R$130,00
Suporte das rodas horizontais | 4 | R$80,00
Suporte das rodas verticais | 4 | R$120,00
Tubo 30x30x3 – suporte do limpador | 2 | R$120,00
TOTAL | | R$2.312,32

Fonte: Autoria Própria (2026).

Para assegurar o funcionamento da estrutura mecânica, foram integrados os componentes eletrônicos responsáveis pelo processamento, controle e alimentação do sistema. A tabela 2 apresenta a relação e os custos atrelados a esses dispositivos.

Tabela 2 – Custos dos componentes elétricos do protótipo

Material | Qtde. | Preço Total
Botões de comando 24 V | 2 | *
Controlador de carga solar 30A 12/24 | 1 | R$ 39,90
Conversor boost 12V – 24V | 1 | R$ 54,61
Conversor buck 12V – 5V | 1 | R$ 20,30
Disjuntor bipolar (20A) | 1 | *
Display LCD 20x4 | 1 | R$ 38,70
Drivers BTS7960 (ponte H) | 3 | R$ 135,00
ESP32-WROOM32 | 1 | R$ 90,04
Módulos bidirecionais | 2 | R$20,30
Optoacoplador de 8 canais PC817 | 1 | R$51,00
Placa para soldagem | 1 | R$20,90
Prensa-cabo | 5 | R$16,50
Sensores de tensão | 2 | R$35,97
Sensores ultrassônicos | 2 | *
Ventoinha | 1 | R$20,80
TOTAL | | R$544,02

Fonte: Autoria Própria (2026).

Além da eletrônica e da mecânica embarcadas no limpador, fez-se necessária a estruturação de um ambiente para a validação prática do projeto. A tabela 3 discrimina os custos gerais de infraestrutura, que contemplam a aquisição de um painel solar de 36 células, bem como os perfis e estruturas de madeira para a fixação do módulo fotovoltaico e dos trilhos de deslocamento.

Tabela 3 – Custos gerais do projeto

Material | Qtde. | Preço Total
Madeiras para estrutura de suportação da placa solar | 12 | R$275,00
Parafusos, roscas e arruelas | Diversos | R$150,00
Perfis de aço para trilhos do limpador | 6 | R$120,00
Placa solar – 36 células, 1x1m | 1 | R$340,00
TOTAL | | R$885,00

Fonte: Autoria Própria (2026).

Dessa forma, para a construção do protótipo e implementação do sistema descrito, os custos totais estão apresentados na Tabela 4.

Tabela 4 – Custos do protótipo

Material | Preço Total
Custos dos componentes mecânicos do protótipo | R$2312,32
Custos dos componentes elétricos do protótipo | R$544,02
Custos gerais do projeto | R$855,00
TOTAL | R$3.711,02

Fonte: Autoria Própria (2026).

4 Resultados e discussões

A avaliação do protótipo foi dividida em duas etapas complementares, com o objetivo de analisar tanto a eficiência mecânica do processo quanto os impactos da remoção de sujeira no desempenho energético do sistema. A partir dos testes e resultados, foi possível analisar a performance do protótipo construído e avaliar os possíveis modos de falha do sistema.

  4.1 Metodologias de avaliação e resultados práticos

A primeira metodologia consistiu na avaliação da capacidade de remoção de partículas por meio de um ensaio controlado, baseado na simulação de sujidade sobre a superfície do painel fotovoltaico. Para isso, utilizou-se farinha de trigo — material de granulometria fina escolhido por sua capacidade de mimetizar o acúmulo de poeira em condições reais de operação, além de oferecer alto contraste visual na superfície da placa. Inicialmente, uma massa conhecida de 200 g do material foi distribuída de maneira uniforme sobre o painel. Em seguida, o sistema de limpeza foi acionado, realizando ciclos completos de operação, definidos pelo deslocamento lateral do protótipo com a escova rotacionando tangente à superfície. Ao final do ciclo, a quantidade de material residual foi coletada e pesada em uma balança de precisão.

Para garantir a robustez e a confiabilidade dos dados, o experimento foi repetido quatro vezes, variando a quantidade de ciclos de varredura (ida e volta) realizados pela escova. A eficiência de limpeza ( η ) foi determinada pela relação entre a massa removida e a massa total aplicada, conforme a equação 1:

η=(m_(removida))/(m_(aplicada))×100 | (1)

As Figuras 17(a) e 17(b) ilustram os ensaios práticos de remoção de partículas sobre a superfície do painel fotovoltaico durante esta primeira etapa de validação.

Figura 17 – Placa solar antes do ensaio 17(a) e placa solar após a limpeza automático 17(b)

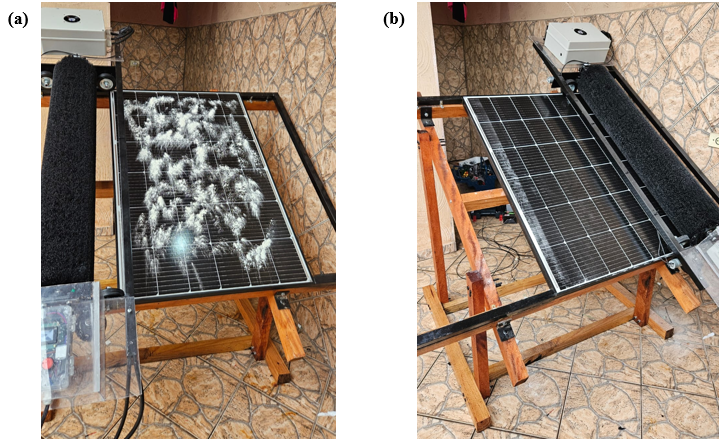
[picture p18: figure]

Fonte: Autoria Própria (2026).

Os dados quantitativos obtidos nesses ensaios estão consolidados na tabela 5, que detalha a massa de farinha aplicada, o número de ciclos executados, a massa residual não removida, a massa efetivamente removida e a eficiência calculada.

Tabela 5 – Resultados obtidos nos testes de capacidade de remoção de partículas

Teste | Massa aplicada (g) | Nº de ciclos | Massa residual (g) | Massa removida (g) | Eficiência (%)
1 | 200 | 1 | 18 | 182 | 91,0%
2 | 200 | 1 | 16 | 184 | 92,0%
3 | 200 | 2 | 8 | 192 | 96,0%
4 | 200 | 2 | 6 | 194 | 97,0%

Fonte: Autoria Própria (2026).

A análise dos dados da tabela 5 evidencia a relação direta entre o tempo de atuação do sistema e a sua eficácia. Nos testes 1 e 2, submetidos a apenas um ciclo de limpeza, a eficiência média ficou em 91,5%. Já nos testes 3 e 4, a aplicação de um segundo ciclo de varredura, que é a ideia de funcionamento principal, reduziu significativamente a massa residual, elevando a eficiência para o patamar de 96,5%. No geral, o sistema apresentou uma eficiência média global de 94,0% na remoção de partículas. Observou-se ainda que o volume residual de sujidade não removida se concentrou majoritariamente nas extremidades estruturais do painel, indicando o limite de alcance mecânico das cerdas da escova, ao passo que toda a área útil central de captação luminosa foi devidamente desobstruída.

A segunda metodologia avaliou o impacto da sujidade na eficiência de geração elétrica. O sistema foi analisado em dois cenários distintos sob as mesmas condições de irradiação solar: com a placa propositalmente suja e com a superfície limpa pelo sistema automatizado. Em ambos os cenários, o painel fotovoltaico foi conectado a uma bateria de motocicletas, utilizando o controlador de carga para assegurar os níveis adequados de tensão. O ensaio consistiu no monitoramento do processo de carregamento durante um período de 3 horas. A avaliação de desempenho energético foi conduzida por meio da medição direta da tensão nos terminais da bateria e da tensão de saída do painel. Dessa forma, comparou-se a curva de elevação da carga (variação de tensão) em ambas as condições, evidenciando as perdas de captação energética causadas pela obstrução na superfície.

A tabela 6 apresenta os resultados do monitoramento de tensão da bateria de 12 V após os períodos de carregamento. Para garantir o rigor comparativo, a tensão inicial da bateria foi descarregada para o mesmo patamar antes do início de cada ciclo. Observou-se ainda que o volume residual de sujidade não removida se concentrou majoritariamente nas extremidades estruturais do painel, indicando o limite de alcance mecânico das cerdas da escova, ao passo que toda a área útil central de captação luminosa foi devidamente desobstruída.

Tabela 6 – Resultados obtidos nos testes de carregamento de carga

Teste | Cenário | Tensão inicial (V) | Tensão final (V) | Ganho de tensão (ΔV)
1 | Placa suja (com farinha) | 11,8 | 12,1 | +0,3 V
2 | Placa limpa (após ciclo) | 11,8 | 12,6 | +0,8 V
3 | Placa suja (com farinha) | 11,7 | 12,0 | +0,3 V
4 | Placa limpa (após ciclo) | 11,7 | 12,4 | +0,7 V

Fonte: Autoria Própria (2026).

Os dados da tabela 6 comprovam a eficácia operacional do projeto. Observa-se que, com a placa obstruída, a taxa de conversão energética foi severamente prejudicada, resultando em um ganho de tensão de apenas 0,3 V no período amostral. Por outro lado, após o acionamento do limpador automatizado, a desobstrução da área de captação permitiu que a placa operasse mais próxima à sua eficiência nominal, refletindo em um ganho de tensão consideravelmente maior (com média de 0,75 V) no mesmo intervalo de tempo de exposição solar.

  4.2 Análise de modos de falha e seus efeitos – FMEA

A fim de avaliar os possíveis modos de falha do sistema a longo prazo e seus impactos operacionais, foi realizada uma análise baseada na metodologia FMEA (Failure Mode and Effects Analysis). Essa ferramenta qualitativa e quantitativa permite mapear vulnerabilidades do projeto e elencar as ações mitigadoras necessárias para garantir a confiabilidade da operação autônoma. O Quadro 1 detalha os principais riscos identificados para o protótipo.

Quadro 1 – Quadro FMEA – possíveis modos de falha e seus impactos

Modo de falha | Causa | Efeito | Severidade | Ocorrência | Detecção | Prioridade de ação | Ação recomendada
Microabrasão no vidro temperado | Presença de partículas rígidas e abrasivas (ex.: areia espessa ou pedras) | Redução irreversível da eficiência de captação e redução da vida útil do painel | 9 | 6 | 7 | Alta | Implementar pré-limpeza ou inspeção
Remoção incompleta de sujeira | Baixa pressão de contato da escova | Perda parcial de eficiência | 7 | 5 | 5 | Média | Ajuste de pressão/rotação
Desgaste das cerdas | Uso contínuo | Redução da eficiência de limpeza | 5 | 4 | 5 | Média | Plano de manutenção preventiva
Falha mecânica no sistema | Sobrecarga ou desalinhamento | Interrupção da operação | 8 | 3 | 4 | Média | Reforço estrutural e inspeção
Acúmulo de sujeira aderida | Contaminantes oleosos ou umidade | Baixa eficiência de limpeza a seco | 5 | 6 | 2 | Média | Avaliar métodos complementares

Fonte: Autoria Própria (2026).

A análise FMEA evidencia que os riscos mais críticos do sistema estão associados à interação direta do protótipo com o ambiente externo e ao desgaste mecânico inerente ao atrito. No entanto, o quadro demonstra que tais riscos podem ser severamente mitigados por meio de estratégias de baixa complexidade, como a manutenção preventiva periódica, o ajuste mecânico pontual e a implementação de restrições via software (como inibir o funcionamento sob chuva ou umidade extrema).

De forma geral, a análise comprova que o sistema apresenta boa confiabilidade operacional. A arquitetura adotada mostra-se plenamente adequada para aplicações práticas, destacando-se como uma solução robusta em cenários que demandam automação de baixo custo e baixo impacto ambiental.

5 Considerações finais

O desenvolvimento do protótipo de sistema automatizado para limpeza de painéis fotovoltaicos demonstrou-se uma solução tecnicamente viável e perfeitamente alinhada às demandas atuais do setor de energia renovável. Considerando o crescimento expressivo da energia solar e os desafios associados à manutenção dos módulos, este trabalho contribui ao propor uma alternativa automatizada, de baixo custo e com potencial de aplicação em diferentes escalas.

Os resultados experimentais evidenciam que o sistema atinge uma eficiência média de 94,0% na remoção de partículas simuladas, validando o princípio de limpeza por contato mecânico com escova rotativa. Além da eficácia mecânica, a validação de eficiência energética comprovou na prática a restauração da capacidade de geração do painel: os ensaios de carregamento registraram um ganho de tensão superior quando a placa estava limpa, em comparação ao cenário obstruído por sujidade. Observou-se também que ciclos adicionais de varredura promovem ganhos incrementais, indicando a existência de um ponto ótimo de operação customizável.

Outro aspecto de suma importância é a adoção do método de limpeza a seco. Essa característica agrega elevado valor ambiental ao projeto, mitigando o desperdício em regiões com restrição hídrica, além de reduzir custos operacionais e simplificar a infraestrutura necessária nas usinas.

A análise de confiabilidade, conduzida por meio da matriz FMEA, permitiu mapear os principais modos de falha e definir estratégias de mitigação precisas. Ficou demonstrado que o sistema apresenta boa robustez operacional e que os riscos inerentes à exposição ambiental e ao desgaste mecânico podem ser facilmente controlados mediante planos de manutenção preventiva adequados.

Do ponto de vista tecnológico, a adoção do microcontrolador ESP32 integrado a uma interface web supervisória proporcionou flexibilidade e acessibilidade à planta. A capacidade de operação remota e monitoramento em tempo real insere o protótipo diretamente no contexto da Internet das Coisas (IoT), estabelecendo uma base sólida para futuras expansões e integrações com sistemas de gestão de energia.

Como propostas para trabalhos futuros, visando garantir maior robustez e viabilidade de mercado, recomendam-se as seguintes modificações estruturais e de controle: (i) a adequação do Grau de Proteção (IP) dos componentes eletrônicos e mecânicos, assegurando maior resistência à exposição contínua à chuva, umidade e poeira; (ii) o aprimoramento da arquitetura elétrica e eletrônica para incluir o mapeamento do status de cada componente, o que facilitaria significativamente os processos de manutenção preventiva e corretiva; e (iii) a incorporação de um sistema de suspensão por molas acopladas aos suportes das rodas de apoio, permitindo que o mecanismo se adapte automaticamente a possíveis desníveis e irregularidades presentes na superfície das placas fotovoltaicas.

Dessa forma, conclui-se que o sistema proposto atende ao objetivo de desenvolver uma solução automatizada para limpeza de painéis fotovoltaicos, apresentando funcionamento autônomo, baixo impacto ambiental e boa capacidade de remoção de sujeira superficial. Apesar das limitações identificadas nos testes energéticos, o trabalho demonstra viabilidade técnica para aplicações futuras, além de abrir possibilidades para aperfeiçoamentos relacionados ao controle do sistema, otimização da eficiência energética e utilização de métodos complementares de limpeza.

Referências

ADEKANBI, M. L.; ALABA, E. S.; JOHN, T. J.; TUNDEALAO, T. D.; BANJI, T. I. Soiling loss in solar systems: a review of its effect on solar energy efficiency and mitigation techniques. Clean Energy Systems, [S.l.], v. 7, p. 100094, 2024. Disponível em: https://www.sciencedirect.com/science/article/pii/S2772783123000444. Acesso em: 28 set. 2025.

ANBER, M.; ABOSHOSHA, M. The impact of using an IoT-based automatic solar panel cleaner on building energy performance. International Journal of Low-Carbon Technologies, [S.l.], v. 19, n. 1, p. 1–8, 2024. Disponível em: https://academic.oup.com/ijlct/article/doi/10.1093/ijlct/ctae137/7733853. Acesso em: 08 set. 2025.

ARAÚJO, F. A. P.; SILVA, J. R.; COSTA, L. M.; et al. Efeitos da acumulação de sujeira sobre o desempenho de módulos fotovoltaicos. Fortaleza: Universidade Federal do Ceará, 2019. Disponível em: https://repositorio.ufc.br/handle/riufc/56363. Acesso em: 08 set. 2025.

ARAUJO, R. et al. Efeitos da acumulação de sujeira sobre o desempenho de módulos fotovoltaicos. Revista Tecnol., Fortaleza, v. 40, n. 2, p. 1–23, dez. 2019. Acesso em: 27 set. 2025.

CASARIN, R. Energia solar atraiu R$ 54,9 bi em investimentos no Brasil em 2024. Portal Solar, [S.l.], 2025. Disponível em: https://www.portalsolar.com.br/noticias/mercado/energia-solar-atraiu-r-54-9-bi-em-investimentos-no-brasil-em-2024. Acesso em: 27 set. 2025.

COSTA, G. C. da. O aumento da demanda, aliado a incentivos e ao avanço da tecnologia, tem contribuído para tornar a energia solar acessível. Entrevista concedida à Absolar, 2024. Disponível em: https://www.absolar.org.br/wp-content/uploads/2025/01/pdf.pdf. Acesso em: 26 set. 2025.

Duarte, M. H. C., Brandão, L., Cardoso, V. L. M., Santos, W. P., 2015. Eficiência das placas fotovoltaicas relacionado a limpeza. Centro Universitário de Patos de Minas, Patos de Minas, Minas Gerais, vol. 1, n.1

HEIN, H. Energia solar atinge 60 GW de capacidade instalada no Brasil. Absolar, 2025. Disponível em: https://www.absolar.org.br/noticias-externas/energia-solar-atinge-60-gw-de-capacidade-instalada-no-brasil/. Acesso em: 27 set. 2025.

LACERDA, F. F.; NEVES, F. M.; CANEL, L. X. C.; LOPES, G. M. B. Conceito de sistemas agrovoltaicos no Nordeste: uma solução de desenvolvimento ecossustentável para o Semiárido nordestino. Revista do Departamento de Geografia, São Paulo, v. 42, p. e189543, 2022. Disponível em: https://revistas.usp.br/rdg/article/view/189543. Acesso em: 28 set. 2025.

Lemos, L. O., Ferreira, Â. M., Jota, P. R. S., Silva, A. G. V., 2016. Efeitos da sujidade no desempenho de módulos fotovoltaicos. In: Congresso Brasileiro de Energia Solar, 6., 2016, Belo Horizonte. Anais... Belo Horizonte: Associação Brasileira de Energia Solar, 2016.

LIMA, Maria Antônia C.; JESUS, Isaque L. de; SOUZA, Anália Emília Barbosa Ferreira de. Clear Sun: sistema sustentável e automatizado para limpeza de placa solares em residências. In: ESCOLA REGIONAL DE COMPUTAÇÃO BAHIA, ALAGOAS E SERGIPE (ERBASE), 24., 2024, Salvador. Anais... Porto Alegre: Sociedade Brasileira de Computação, 2024. p. 235-240. Disponível em: https://sol.sbc.org.br/index.php/erbase/article/view/33895. Acesso em: 08 set. 2025.

LIMA JÚNIOR, C.; SOUZA, T. L. S. Energia solar e poluição do ar: abordagem experimental educativa. Revista Brasileira de Educação Ambiental, São Paulo, v. 20, n. 3, p. 69–68, 2025. Disponível em: https://periodicos.unifesp.br/index.php/revbea/article/download/19656/13883/88429. Acesso em: 28 set. 2025.

MACIEL, Mauricio Alencar; LEOCADIO, Vitor Lima; JOAQUIM, Victor da Silva; SILVA, Wesley Sousa da; COSTA, Mauricio Caldora. Robô limpador de painel solar. 2023. Trabalho de Conclusão de Curso (Bacharelado em Engenharia Elétrica) – Universidade Anhembi Morumbi, São Paulo, 2023.

Maghami, M. R. et al., 2016. Power loss due to soiling on solar panel: A review. Renewable and Sustainable Energy Reviews, v. 59, p. 1307-1316.

Mani, M., Pillai, R., 2010. Impact of dust on solar photovoltaic (PV) performance: Research status, challenges and recommendations. Renewable and Sustainable Energy Reviews, v. 14, p. 3124-3131.

MCKINSEY & COMPANY. A future that works: automation, employment, and productivity. 2017. Disponível em: https://www.mckinsey.com/~/media/McKinsey/Industries/Healthcare%20Systems%20and%20Services/Our%20Insights/Automation%20at%20scale%20The%20benefits%20for%20payers/Aut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. Acesso em: 08 set. 2025.

MELLO, W. Z.; TEIXEIRA, E. C.; SILVA, J. A. Study of chemical elements in atmospheric precipitation in South Brazil. Atmospheric Environment, v. 35, n. 18, p. 3091–3101, 2001. Disponível em: https://www.researchgate.net/publication/223007708_Study_of_chemical_elements_in_atmospheric_precipitation_in_South_Brazil. Acesso em: 08 set. 2025.

MONDAL, Surajit; MONDAL, Amit Kumar; SHARMA, Abhishek; DEVALLA, Vindhya; RANA, Sravendra; KUMAR, Suresh; PANDEY, Jitendra Kumar. An overview of cleaning and prevention processes for enhancing efficiency of solar photovoltaic panels. Current Science, Bangalore, v. 115, n. 6, p. 1065–1077, 25 set. 2018. Disponível em: https://www.jstor.org/stable/e26978337. Acesso em: 28 set. 2025.

SILVA, Luzilene Souza; ASSUNÇÃO, Ronaldo Furtado de; ROCHA SOBRINHO, Demetrius Clemente da; FREITAS, Ericka da Silva; ASSUNÇÃO, Welton Raiol de. Avaliação de custo-benefício da utilização de energia fotovoltaica. Revista Científica Multidisciplinar Núcleo do Conhecimento (RCT), v. 5, n. 9, 2019. ISSN 2447-7028.

SOUSA, Deysiane Dandara Rodrigues de; FERNANDES NETO, André Pedro. Automatização da manutenção de placas solares: sustentabilidade e eficiência energética. 2024. Trabalho de Conclusão de Curso (Engenharia de Produção) – Universidade Federal Rural do Semiárido, Mossoró, 2024.

TITARA, D. O futuro da energia solar no Brasil: crescimento e desafios. Eletrolar News: Setor Elétrico, São Paulo, p. 62–72, 2024. Disponível em: https://www.absolar.org.br/wp-content/uploads/2025/01/pdf.pdf. Acesso em: 26 set. 2025.

VIEIRA JÚNIOR, A. A. Impacto da Limpeza de Painéis Fotovoltaicos para Melhor Produtividade. Goiânia, 2021. Disponível em: <https://repositorio.pucgoias.edu.br/jspui/bitstream/123456789/3228/1/IMPACTO%20DA%20LIMPE ZA%20DE%20PAIN%C3%89IS%20FOTOVOLTAICOS%20PARA%20MELHOR%20PRODUTIV IDADE.pdf>. Acesso em: 25 jan 2025.

4 Curso Superior de Bacharelado em Engenharia de Controle e Automação - São Bernardo do Campo - SP - Brasil - 08 a 11 de junho de 2026 V-06

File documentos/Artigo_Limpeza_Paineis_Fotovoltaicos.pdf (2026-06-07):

Curso Superior de Bacharelado em Engenharia de Controle e Automação - São Bernardo do Campo - SP -Brasil - 08 a 11 de junho de 2026

V-06

Protótipo de sistema automatizado de limpeza de placas solares com controle web e alimentação autônoma

Augusto Araujo Bueno, Bruno Kayki Ribeiro de Souza, Gustavo da Paz Coelho, Itamar Silva de Sousa Júnior, Rubens Melo de Souza.

1

Me. Antônio José do Couto Pitta

Resumo

A eficiência de módulos fotovoltaicos é frequentemente reduzida pelo acúmulo de sujidade, exigindo limpezas periódicas para evitar perdas de geração (Araujo et al., 2019; Adekanbi, 2024). Neste contexto, este trabalho apresenta um protótipo automatizado para limpeza a seco de placas solares, com controle web e alimentação autônoma, visando otimizar a manutenção, reduzir custos e preservar a eficiência energética. A metodologia englobou o projeto mecânico no Autodesk Inventor, o elétrico no EPLAN Electric P8 e a interface web no Visual Studio Code, integrada ao Firebase. O hardware baseia-se no módulo ESP32-WROOM-32, motores DC acionados por pontes H (BTS7960), sensores de tensão e ultrassônicos, controlador de carga e escova cilíndrica de nylon. Foram realizados testes experimentais de remoção de partículas e desempenho energético. Os resultados comprovaram 94,0% de eficiência média na remoção de sujidade simulada, garantindo operação autônoma e monitoramento remoto em tempo real. Embora os ganhos energéticos tenham sido pouco expressivos devido à pequena escala do painel utilizado, testes de curta duração e possíveis variações na irradiação solar, o sistema validou sua viabilidade técnica, baixo impacto ambiental e potencial para aplicações fotovoltaicas.

Palavras-chave: Sistemas fotovoltaicos. Automação de limpeza. Controle Web. Alimentação Autônoma. Remoção de partículas.

Abstract

The efficiency of photovoltaic modules is frequently reduced by the accumulation of soiling, requiring periodic cleaning to prevent generation losses (Araujo et al., 2019; Adekanbi, 2024). In this context, this work presents an automated prototype for the dry cleaning of solar panels, with web control and autonomous power supply, aiming to optimize maintenance, reduce costs, and preserve energy efficiency. The methodology encompassed the mechanical design in Autodesk Inventor, the electrical design in EPLAN Electric P8, and the web interface in Visual Studio Code, integrated with Firebase. The hardware is based on the ESP32-WROOM-32 module, DC motors driven by H-bridges (BTS7960), voltage and ultrasonic sensors, a charge controller, and a cylindrical nylon brush. Experimental tests were conducted for particle removal and energy performance. The results proved an average efficiency of 94.0% in cleaning simulated soiling, ensuring autonomous operation and real-time remote monitoring. Although the energy gains were not highly significant due to the small scale of the panel used, the short duration of the tests, and possible variations in solar irradiance, the system validated its technical feasibility, low environmental impact, and potential for photovoltaic applications.

Keywords: Photovoltaic systems. Cleaning automation. Web control. Autonomous power supply. Particle removal.

1 Faculdade Engenheiro Salvador Arena, Centro Educacional da Fundação Salvador Arena, Estrada dos Alvarengas, 4001
- São Bernardo do Campo - SP

### 1 Introdução

A crescente procura por soluções sustentáveis na geração de eletricidade tem promovido mudanças significativas na matriz energética mundial. Nesse contexto, a energia solar desponta como uma alternativa estratégica, limpa e renovável, capaz de reduzir impactos ambientais e contribuir para a diversificação da matriz (Titara, 2024).
Nos últimos anos, esse movimento também se intensificou no Brasil, onde a energia solar tornou-se a segunda maior fonte elétrica do país, atrás apenas das hidrelétricas. O aumento da demanda, aliado a incentivos e ao avanço tecnológico, tem ampliado o acesso da população a essa modalidade (Costa, 2024). Em 2024, o país possuía aproximadamente 43 GW de potência instalada, e em 2025 atingiu a marca de 60 GW, passando a representar mais de 23% de toda a potência elétrica nacional (Absolar, 2025). Esse avanço trouxe impactos importantes, como a redução das emissões de CO₂, a geração de empregos e a captação de investimentos em diferentes regiões (Casarin, 2025).
No entanto, a consolidação da energia solar também evidencia desafios técnicos relacionados à operação e manutenção dos sistemas instalados. A eficiência e o rendimento dos módulos fotovoltaicos estão diretamente condicionados à manutenção preventiva, em especial à limpeza das superfícies. A exposição contínua ao ambiente favorece o acúmulo de poeira, partículas provenientes da poluição atmosférica, folhas e outros resíduos, que atuam como barreiras à incidência da radiação solar sobre as células fotovoltaicas, comprometendo significativamente seu desempenho (Araujo et al., 2019). De acordo com Adekanbi (2024), “[...] as perdas anuais de energia devido ao soiling podem variar entre 3% e 5% em regiões de clima moderado, mas ultrapassam 30% em áreas áridas ou altamente poluídas.”. Esse fator assume particular relevância no Brasil, sobretudo em centros urbanos, onde o crescimento progressivo dos índices de poluição intensifica a deposição de partículas sobre os módulos e acelera a queda de eficiência (Lima; Souza, 2025).
A metodologia de limpeza convencional, predominantemente manual, apresenta limitações importantes. Entre os principais entraves destacam-se o acesso restrito a estruturas instaladas em telhados ou locais elevados, a dependência de mão de obra especializada, o custo elevado das operações periódicas e o risco de danos aos módulos quando a limpeza é realizada de forma inadequada (Mondal et al., 2018). Além disso, a realização esporádica dessas manutenções não acompanha o ritmo do acúmulo de sujeira, resultando em períodos prolongados de operação dos módulos em condições subótimas, uma vez que a presença de partículas como poeira, poluição e detritos reduz a eficiência e a capacidade de geração de energia dos sistemas fotovoltaicos (Sousa, Neto, 2024).
Diante desse cenário, a automação da limpeza se apresenta como uma alternativa promissora. A integração de microcontroladores a uma interface web supervisória possibilita o monitoramento remoto e o acionamento automático do sistema de limpeza, reduzindo a necessidade de intervenção manual e aumentando a confiabilidade da geração (Mello et al., 2003). O diferencial está na proposta de desenvolver uma solução de baixo custo com potencial de escalabilidade para diferentes tipos de empreendimentos de maior dimensão, como sistemas fotovoltaicos residenciais e usinas solares. Essa característica amplia a viabilidade da tecnologia e fortalece o papel da energia solar como componente essencial da transição energética sustentável (Lacerda; Canel; Lopes, 2022).
Nesse contexto, o objetivo geral do projeto se dá no desenvolvimento de um sistema de limpeza automatizado para placas fotovoltaicas utilizando controle web e alimentação autônoma, de modo a maximizar a eficiência energética e reduzir os custos de manutenção. Dessa forma, devem ser cumpridos os seguintes objetivos específicos:
a) Projetar a estrutura mecânica da plataforma de limpeza adequada para os módulos fotovoltaicos, garantindo cobertura completa e eficiência operacional;
b) Desenvolver alternativa elétrica para o sistema que seja alimentado pelo painel solar;

c) Desenvolver a lógica de controle do microcontrolador para a automação da limpeza e implementar a interface web supervisória para acionamento remoto e monitoramento das variáveis do sistema;
d) Projetar o mecanismo de limpeza garantindo contato tangencial com a superfície do painel fotovoltaico e livre deslizamento ao longo de seu comprimento, visando a adaptabilidade do sistema a instalações com maior quantidade de painéis;
e) Avaliar a eficiência energética dos módulos antes e depois da limpeza automatizada, visando atingir um resultado de 85% de limpeza.

### 2 Referencial teórico

Inicialmente, serão apresentados trabalhos acadêmicos que estudam o impacto do acúmulo de sujidade na eficiência de sistemas fotovoltaicos, bem como experiências com sistemas automatizados de limpeza de painéis e a validação de sua efetividade, fornecendo suporte conceitual e técnico para o desenvolvimento do sistema proposto.

### 2.1 Impacto da sujidade sobre o desempenho de sistemas fotovoltaicos

O estudo realizado por Júnior, Cruz e Amaral (2018) analisou os efeitos do acúmulo de sujeira sobre as placas de um sistema fotovoltaico real, quantificando a redução provocada na geração de energia. Segundo Lemos et al. (2016), o impacto da sujidade pode ocasionar reduções de desempenho entre 4% e 26,3%, variando conforme o tipo de célula, as características da poeira e as condições climáticas locais. Fatores como a rugosidade da superfície dos módulos, sua inclinação, a velocidade dos ventos e a frequência de chuvas são igualmente determinantes no acúmulo de sujeira (Maghami et al., 2016; Mani; Pillai, 2010).
A sujidade é definida como o acúmulo de resíduos inorgânicos na superfície dos módulos, como poeira, pólen, carbono amorfo proveniente da queima de combustíveis e resíduos oleosos oriundos de processos produtivos e tráfego de veículos (Lemos, 2016). Como a geração elétrica depende da incidência de fótons na superfície dos módulos, qualquer barreira física reduz a absorção de energia e compromete a produção (Duarte et al., 2015). De acordo com Villalva (2015), a eficiência das células fotovoltaicas varia geralmente entre 14% e 20%, dependendo da tecnologia utilizada, tornando qualquer redução por sujidade um fator relevante para o desempenho do sistema.
Júnior, Cruz e Amaral (2018) constataram que os índices de geração decaem em média 20% em decorrência do acúmulo de sujidade, estabelecendo um intervalo mínimo de periodicidade de limpeza dos módulos. O trabalho evidenciou ainda que, em períodos de chuvas frequentes, a limpeza natural permite reduzir substancialmente ou eliminar a necessidade de limpeza manual das placas.

### 2.2 Automatização da manutenção de placas solares

Sousa e Neto (2024) propõem o uso da automação como solução para reduzir custos operacionais na manutenção de módulos fotovoltaicos, destacando que o acúmulo de sujeira pode provocar perdas de até 25% na geração de energia, além de causar danos às células devido ao aquecimento desigual e à formação de fissuras.
No estudo de Vieira Júnior (apud Sousa; Neto, 2024), a coleta de dados realizada cinco meses antes e cinco meses após a limpeza dos módulos revelou um aumento de 12,08% na geração logo após a limpeza, com decréscimo progressivo de até 7,56% ao longo dos meses seguintes, confirmando a necessidade de limpezas periódicas.
Com base nesses resultados, Sousa e Neto (2024) propõem um sistema automatizado composto por sensores de sujidade, sistema de ativação automática por relés e atuadores, bomba de água e controlador

(Arduino ou CLP), concluindo que a automação da manutenção representa uma estratégia eficaz para conciliar eficiência energética e viabilidade econômica.

### 2.3 Sistema sustentável e automatizado para limpeza de placa solares em residências

O trabalho apresentado por Lima, Jesus e Souza (2024) descreve o desenvolvimento do projeto Clear Sun, um sistema automatizado de limpeza de placas solares voltado a residências e telhados de difícil acesso, com o objetivo de maximizar a captação de energia e reduzir custos operacionais com manutenção manual. O sistema propõe a utilização de um escovão posicionado transversalmente à placa, movimentado por um motor DC para rotação e deslocado ao longo da superfície por um motor de passo controlado por Arduino Nano e ESP32, com uso de bomba de água para a limpeza úmida — desligada automaticamente por um sensor de chuva quando umidade é detectada nas placas.
Os autores destacam que muitos usuários não realizam a limpeza necessária dos painéis, sendo que em alguns casos a higienização ocorre apenas de dois a três anos após a instalação, comprometendo significativamente a eficiência energética do sistema. Embora o projeto represente um avanço na automação da manutenção, a dependência de recursos hídricos pode ser uma limitação em regiões com escassez de água ou sem acesso fácil a reservatórios, aspecto contornado pelo sistema proposto no presente trabalho, que adota limpeza a seco.

### 2.4 Limpador automático de painéis solares baseado em IoT em edifícios no Egito

Um estudo desenvolvido por Anber e Aboshosha (2024) investigou o uso de um limpador automático de painéis solares baseado em IoT no Egito, em região de clima desértico. O objetivo do trabalho foi mensurar a influência da poeira sobre os módulos fotovoltaicos e verificar a efetividade da limpeza automatizada. Os autores constataram que a eficiência dos painéis, reduzida em até 89,33% devido ao acúmulo de poeira, pôde ser restaurada para 99,4% de sua potência original por meio do sistema automatizado, demonstrando a relevância da automação na manutenção de painéis solares.
A literatura indica que a automação da limpeza, quando aliada ao monitoramento em tempo real por meio de IoT, constitui uma estratégia tecnológica eficaz para mitigar essas perdas. Nesse sentido, a figura 1 apresenta a proposta deste trabalho, que utiliza uma interface IoT, por meio de um celular, para controle de um eixo horizontal de limpeza (Anber; Aboshosha, 2024).
Os testes experimentais demonstraram que a aplicação do sistema de limpeza automática baseado em IoT foi capaz de recuperar a eficiência dos painéis para cerca de 99,5% do valor original, evidenciando a alta eficácia do método na remoção de sujeira e na restauração da capacidade de geração de energia (Anber; Aboshosha; 2024).

Figura 1 – Limpador automático de painéis solares baseado em IoT com monitoramento remoto

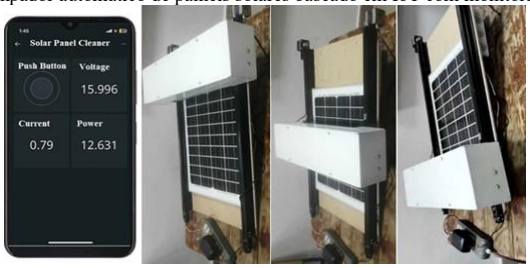
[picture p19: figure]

Fonte: Anber e Aboshosha (2024).

### 2.5 Robô limpador de painel solar

O trabalho apresentado por Maciel et al. (2023) descreve o desenvolvimento de um robô limpador de painéis fotovoltaicos, conforme ilustrado na figura 2, com o objetivo de otimizar a eficiência na geração de energia por meio de limpeza periódica e semiautomatizada. A principal inovação do protótipo é a adoção de limpeza a seco, dispensando o uso de água ou produtos químicos, o que reduz o impacto ambiental e preserva a integridade das placas.

Figura 2 – Robô limpador para limpeza a seco de placas

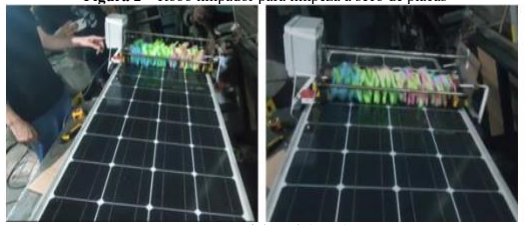
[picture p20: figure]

Fonte: Maciel et al. (2023).

O robô utiliza escovas de microfibra rotativas para remover poeira e partículas que podem reduzir em até 30% a eficiência dos módulos solares, mantendo a superfície sem riscos de danos como “hot spots”. Sua estrutura em ferro garante robustez, enquanto o controle por Arduino Uno gerencia os motores de corrente contínua e os sensores ultrassônicos, assegurando a movimentação segura e os ciclos de limpeza (Maciel et al., 2023).
Os testes de eficiência foram conduzidos com farinha de trigo como sujeira simulada, distribuída em quatro etapas de 250 g cada sobre a superfície da placa. Ao final dos ciclos de limpeza, os autores constataram uma eficiência média de 83,3% na remoção da sujeira simulada, confirmando a viabilidade prática do protótipo. A análise financeira realizada pelos autores indicou ainda que a falta de limpeza periódica pode resultar em perdas anuais significativas, reforçando o retorno econômico de soluções automatizadas de manutenção (Maciel et al., 2023).

### 3 Metodologia

Para o desenvolvimento do protótipo do sistema de limpeza automatizado, foram realizadas as seguintes etapas: estudo do método de limpeza, desenvolvimento dos projetos mecânico e elétrico, definição da lógica de funcionamento e programação de controle, implementação do método de comunicação entre o microcontrolador e as interfaces, desenvolvimento da interface web e da interface física local e, por fim, validação do sistema por meio de testes de funcionamento.
O protótipo é composto pelos seguintes componentes principais: um microcontrolador ESP32, três drivers de acionamento de motores BTS7960, dois motores DC de alto torque 5840-555 de 24 V, um motor DC RS555 de 12 V, dois sensores de tensão, dois sensores ultrassônicos, um display LCD 20x4 com comunicação I2C, dois botões, um controlador de carga solar, duas baterias de 12 V e uma escova de limpeza cilíndrica. O diagrama funcional, apresentado na figura 3, ilustra a arquitetura do sistema e a interação entre seus componentes.

Figura 3 – Diagrama funcional: arquitetura e interação entre subsistemas

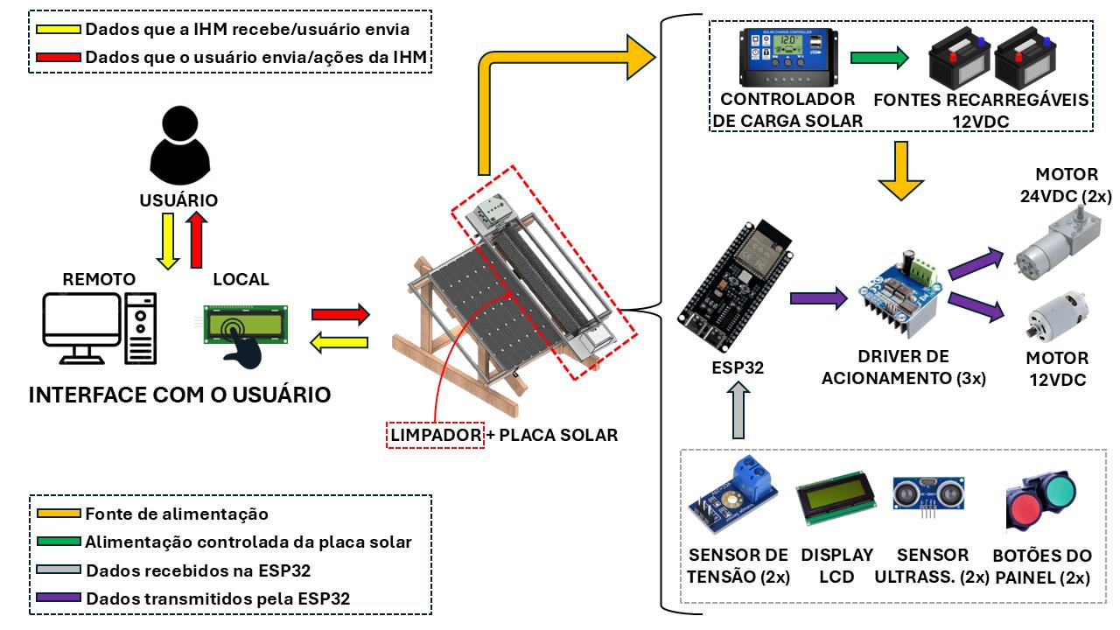
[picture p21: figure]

Fonte: Autoria Própria (2026).

Cabe destacar que o protótipo não foi desenvolvido sobre um painel fotovoltaico de dimensão padrão, uma vez que a aquisição de componentes em escala real excederia os recursos disponíveis. Optou-se, portanto, pela construção em escala reduzida, utilizando uma placa fotovoltaica com dimensões aproximadas de 1135 × 730 × 35 mm, composta por 36 células. Para a realização dos testes, foi desenvolvida uma estrutura de apoio em madeira, responsável por sustentar a placa fotovoltaica e, consequentemente, o limpador, que opera sob a superfície da placa. Essa abordagem permite demonstrar o funcionamento do sistema proposto e validar os princípios de automação aplicados ao mecanismo de limpeza.
O sistema de limpeza pode ser acionado de forma manual, por meio do painel de controle ou das interfaces desenvolvidas, ou de forma automática, mediante a definição de um intervalo de tempo para a periodicidade da limpeza. Os comandos são enviados à ESP32, responsável pelo processamento da lógica de controle e pelo acionamento dos drivers e motores. O monitoramento da posição do limpador é realizado por dois sensores ultrassônicos HC-SR04.
A alimentação do sistema é provida por duas baterias de 12 V, cuja tensão é distribuída e convertida para diferentes níveis ao longo do circuito: um conversor elevador fornece 24 V para os motores de deslocamento do limpador (modelo 5840-555), enquanto os 12 V nativos alimentam o motor da escova cilíndrica (modelo RS555) e um conversor abaixador fornece 5 V para a lógica de controle. O acionamento e reversão de todos os motores são controlados por pontes H BTS7960. As baterias são recarregadas por um controlador de carga alimentado pelo próprio painel fotovoltaico, aproveitando a energia gerada pelo sistema para sua autonomia operacional.
Para o monitoramento da alimentação do sistema, proveniente das baterias, utilizam-se dois sensores de tensão, cujos dados são enviados à ESP32, permitindo uma análise indireta do desempenho do painel fotovoltaico.

### 3.1 Método de limpeza e material da escova

Com base nos referenciais teóricos estudados, o método adotado pelo sistema de limpeza automatizado desenvolvido é a limpeza a seco, realizada por meio de um eixo rotativo acoplado a uma escova cilíndrica que percorre a superfície do painel por contato mecânico, conforme ilustrado na figura 4. O princípio de funcionamento consiste na rotação da escova em uma velocidade adequada, promovendo a remoção de partículas depositadas sobre a superfície por meio de contato mecânico controlado. A geometria cilíndrica permite uma distribuição uniforme das forças de contato ao longo da área de limpeza, garantindo maior eficiência na remoção da sujeira sem concentrar esforços excessivos em pontos específicos.

Figura 4 – Método de limpeza a seco proposto para o sistema de limpeza automatizado

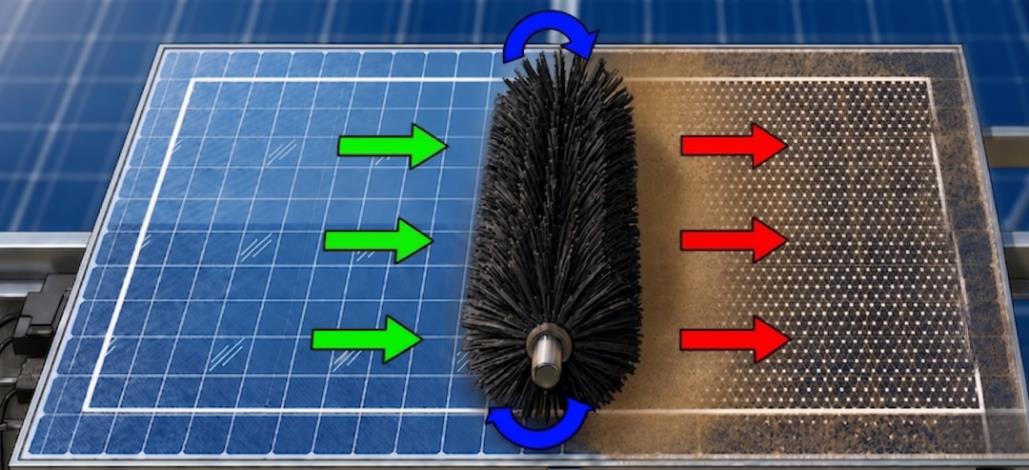
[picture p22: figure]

Fonte: Autoria Própria (2026).

A adoção do sistema de limpeza a seco justifica-se por aspectos técnicos, ambientais e operacionais. Esse método elimina o consumo hídrico, fator crucial para regiões que enfrentam escassez de água. Além disso, evita a formação de resíduos minerais provenientes da evaporação, os quais podem comprometer o desempenho dos módulos. Outro benefício relevante é a mitigação de riscos elétricos durante a operação, pois a ausência de água dispensa a necessidade de desligamento do sistema, garantindo maior continuidade na geração de energia. Por fim, a eliminação de componentes hidráulicos simplifica a estrutura do sistema, reduzindo os custos operacionais e facilitando sua aplicação em ambientes remotos e com soluções automatizadas.
Tomando como referência o painel fotovoltaico de 36 células, o dimensionamento da escova foi realizado por meio de projeto sob medida no software Autodesk Inventor, resultando nas seguintes especificações: diâmetro externo de 200 mm, comprimento de 1100 mm, furo central de 25 mm para acoplamento ao eixo e base estrutural de 75 mm, com cerdas de nylon preto com espessura entre 0,20 mm e 0,30 mm, conforme ilustrado na figura 5(a). A figura 5(b) apresenta a escova fabricada conforme o projeto, composta por cerdas de nylon preto e reforçada para uso contínuo.

Figura 5 – Vista isométrica da escova em 3D 5(a) e perspectiva frontal da escova fabricada 5(b)

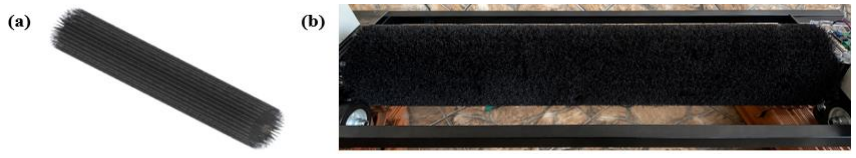
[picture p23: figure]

Fonte: Autoria Própria (2026).

A escolha do nylon como material das cerdas contribui para a preservação da integridade do vidro do módulo fotovoltaico, uma vez que apresenta dureza inferior à do vidro, reduzindo o risco de microabrasões. Esse fator é fundamental para manter a eficiência energética do sistema ao longo do tempo, evitando perdas associadas a danos superficiais.
Dessa forma, o método de limpeza adotado estabelece as bases para o desenvolvimento estrutural do sistema, uma vez que as características geométricas e operacionais da escova influenciam diretamente na concepção mecânica do conjunto. Assim, torna-se necessária a modelagem do limpador horizontal, considerando aspectos como dimensões, distribuição de massa, pontos de fixação e integração dos componentes responsáveis pelo deslocamento e acionamento do sistema.

### 3.2 Modelagem mecânica

Após a definição do método de limpeza e do material da escova, o projeto mecânico foi modelado no software Autodesk Inventor com base nos componentes adquiridos para o protótipo. Foram definidos os principais elementos estruturais do limpador, como suportes de fixação, eixo de movimento, base dos motores e proteções, sendo cada peça modelada individualmente e posteriormente integrados ao conjunto. A figura 6(a) apresenta a vista explodida do projeto mecânico em 3D, enquanto a figura 6(b) mostra a lista de componentes e suas respectivas massas, resultando em um peso total aproximado do conjunto de 23,75 kg.

Figura 6 – Montagem em 3D completa 6(a) e lista de peças 6(b)

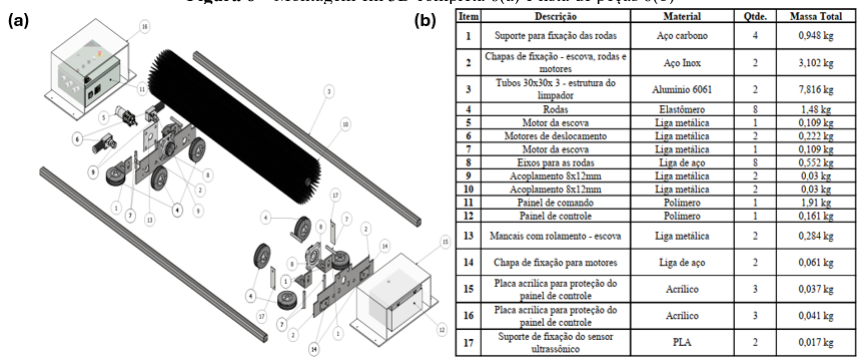
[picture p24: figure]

Fonte: Autoria Própria (2026).

A estrutura do limpador é composta por perfis e chapas de aço soldadas, que integram os suportes das rodas, a base dos motores e o alojamento dos painéis de comando, formando um conjunto rígido e funcional. A Figura 7(a) apresenta a vista isométrica do projeto tridimensional, enquanto a Figura 7(b) ilustra o limpador horizontal construído.

Figura 7 – Vista isométrica em 3D 7(a) e perspectiva frontal do protótipo montado 7(b)

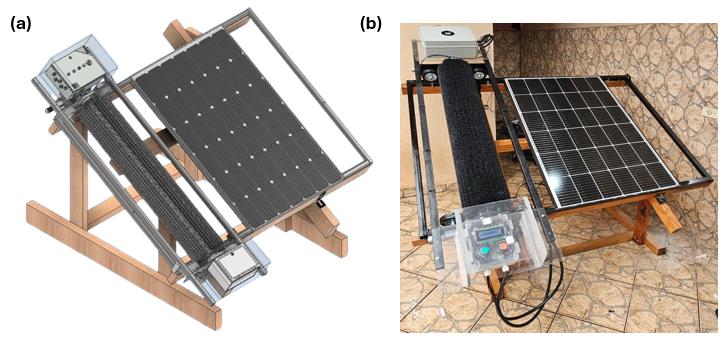
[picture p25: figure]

Fonte: Autoria Própria (2026).

O projeto foi concebido com base no princípio da modularidade: o limpador é sobreposto ao painel fotovoltaico, sem fixação permanente, permitindo sua remoção e reinstalação em outros conjuntos de placas, o que amplia a aplicabilidade do sistema e reduz custos de implantação. Essa concepção modular, aliada às características geométricas e à massa total do conjunto, determinou as demandas operacionais envolvidas no deslocamento e acionamento do sistema, influenciando diretamente o dimensionamento elétrico e a arquitetura do sistema de controle.
Cabe ressaltar que, embora a massa total calculada para o conjunto do limpador seja de aproximadamente 23,75 kg, essa carga não é aplicada de forma pontual sobre a superfície do módulo fotovoltaico. O projeto estrutural distribui uniformemente o peso por meio de oito rodas fabricadas em elastômero, material que atua diretamente na absorção de vibrações e na acomodação mecânica da estrutura, mitigando significativamente o risco de microfissuras ou fadiga estrutural do vidro temperado em longo prazo. Além disso, em uma futura adaptação do protótipo para aplicação comercial, pretende-se otimizar a estrutura do equipamento e substituir os perfis e chapas atuais por materiais mais leves, como alumínio estrutural ou polímeros de engenharia, reduzindo significativamente a massa total do conjunto.
Dessa forma, faz-se necessário o desenvolvimento de um painel elétrico capaz de integrar os motores, sensores e dispositivos de proteção, garantindo o funcionamento seguro e automatizado do sistema.

### 3.3 Circuito elétrico

O projeto elétrico foi desenvolvido no software EPLAN Electric P8, ferramenta de engenharia que facilita a visualização das ligações e a montagem do circuito. O diagrama elétrico pode ser observado na figura 8.

Figura 8 – Diagrama elétrico do projeto


Fonte: Autoria Própria (2026).

Dado que o sistema integra componentes de acionamento de alta tensão e componentes de controle mais sensíveis, optou-se pela separação em dois painéis distintos: o painel de comando, destinado aos componentes de acionamento e maior tensão, e o painel de controle, de menor porte, responsável por abrigar os componentes eletrônicos mais sensíveis.
O painel de comando, apresentado na figura 9, abriga os seguintes componentes: controlador de carga solar (A), responsável pela gestão de corrente e tensão do circuito; disjuntor bipolar (B), para proteção exclusiva do controlador de carga; conversor elevador de tensão (C), responsável pela conversão de 12 V para 24 V; e três drivers BTS7960 (D), sendo dois destinados aos motores de deslocamento e um ao motor de rotação da escova. O painel conta ainda com prensas-cabo (E), para entrada e saída de cabos, e uma ventoinha (F), para dissipação do calor gerado pelos componentes em operação.

Figura 9 – Vista interna dos componentes do Painel de Controle.


Fonte: Autoria Própria (2026).

O painel de controle, apresentado nas Figuras 10(a) e 10(b), abriga os seguintes componentes: controlador ESP32 (A), microcontrolador central responsável pela lógica e controle do sistema; módulo optoacoplador de 8 canais (B), utilizado para leitura dos botões de 24 V, protegendo a ESP32 contra sinais de tensão incompatíveis; conversores de nível bidirecional (C) e sensores de tensão (D), soldados em placa de soldagem, sendo os primeiros responsáveis pela elevação do sinal de 3,3 V para 5 V para acionamento das pontes H, e os segundos pelo monitoramento da tensão das baterias; conversor abaixador de tensão (E), que converte 24 V para 5 V para alimentação da lógica de controle; display LCD (F), utilizado como interface visual local; botões de 24 V verde (G) e vermelho (H), para acionamentos manuais e interação com o display; e prensas-cabo (I), para entrada e saída de cabos.

Figura 10 – Disposição interna do painel de controle 10(a) e disposição externa do painel de controle 10(b).


Fonte: Autoria Própria (2026).

A alimentação do sistema ocorre por meio de duas baterias de 12 V, mantidas carregadas por um ciclo de autonomia energética provido pela própria placa fotovoltaica do protótipo, conforme ilustrado na figura 11. O ciclo se inicia com a geração de energia pelo painel fotovoltaico, que fornece tensão de aproximadamente 24 V e corrente nominal de até 7,55 A. Essa energia é gerida pelo controlador de carga solar, responsável por regular a tensão e a corrente de entrada, garantindo o carregamento seguro das baterias. Uma vez carregadas, as baterias fornecem alimentação ao sistema de controle e acionamento, que por sua vez comanda o limpador durante os ciclos de limpeza. Concluída a operação, o sistema retorna ao estado de monitoramento, aguardando o próximo ciclo programado, enquanto o painel fotovoltaico continua recarregando as baterias.

Figura 11 – Ciclo da alimentação autônoma do protótipo.


Fonte: Autoria Própria (2026).

### 3.4 Lógica de funcionamento

O sistema de limpeza foi concebido com base em uma estratégia de operação por intervalos de tempo configuráveis pelo usuário. Nessa abordagem, o operador define os períodos ao longo do dia em que a limpeza deve ser executada, e o sistema realiza automaticamente dois ciclos completos a cada intervalo programado. Cada ciclo consiste em uma passagem de ida e uma passagem de volta do limpador ao longo da superfície do painel fotovoltaico. A repetição consecutiva das passagens tem por objetivo maximizar a remoção de partículas e resíduos, compensando a ausência de um sensor de feedback que ateste diretamente o grau de limpeza atingido.
A execução de cada ciclo é controlada pelo acionamento coordenado dos três motores DC e monitorada pelos sensores ultrassônicos dispostos nas extremidades do percurso. A atuação sequencial desses sensores indica a conclusão de cada passagem, comandando a inversão do movimento ou a interrupção do ciclo conforme a etapa em execução. A sequência lógica completa desse processo é ilustrada pelo fluxograma da figura 12.

Figura 12 – Fluxograma do processo


Fonte: Autoria Própria (2026).

Além do modo automático descrito e apresentado no fluxograma, o sistema oferece um modo manual de operação, no qual o usuário pode acionar a limpeza a qualquer momento por meio da interface web ou da interface física local, independentemente dos intervalos programados. Essa dualidade de controle busca garantir flexibilidade operacional e assegura a continuidade do funcionamento mesmo em situações em que o agendamento automático não seja suficiente ou adequado.
O firmware do sistema foi desenvolvido no Arduino IDE com o framework Arduino para ESP32. A escolha da ESP se justifica pela conectividade Wi-Fi nativa, que viabiliza a integração com serviços em nuvem e o controle remoto dos periféricos, aspectos fundamentais para a proposta de controle web adotada no projeto.

### 3.5 Comunicação

Como solução de comunicação entre o microcontrolador e as interfaces de controle, foi adotado o Firebase, plataforma de desenvolvimento em nuvem oferecida pela Google. A plataforma oferece três recursos que potencializam o projeto: (i) hospedagem de dados em nuvem sem necessidade de servidor próprio, de modo que qualquer dispositivo conectado à internet acessa os dados da ESP32 diretamente; (ii) sincronização em tempo real por meio do Realtime Database, um banco de dados NoSQL que atualiza simultaneamente todos os clientes conectados, aspecto especialmente relevante dado que o sistema conta com interface web e interface física operando em paralelo; e (iii) o Firebase Authentication, que restringe o acesso às informações apenas a usuários previamente cadastrados na plataforma.
No banco de dados, todas as variáveis de monitoramento e controle remoto estão organizadas em um único nó estruturado, contemplando: comandos manuais, modo de operação (manual/automático), status dos motores e sentido de rotação (inferido pelo acionamento dos bits da ponte H), status de comunicação com a ESP32, periodicidade configurada para os ciclos de limpeza, contagem de ciclos realizados e tensão individual das duas baterias. Cada variável possui valores predefinidos na estrutura do banco, tratados e selecionados internamente pela programação da ESP32, conforme ilustrado na figura 13.

Figura 13 – Variáveis de tratativa remota no Firebase


Fonte: Autoria Própria (2026).

A comunicação entre a ESP32, o Firebase e a Interface Web são estabelecidos por meio de três chaves de configuração únicas por projeto: o apiKey, que identifica a aplicação na plataforma; o authDomain, responsável pelo gerenciamento do fluxo de autenticação; e a databaseURL, que aponta para o banco de dados onde estão armazenadas todas as variáveis do sistema.

### 3.6 Interface web

A interface web tem como objetivo permitir o monitoramento e controle remoto do sistema por qualquer dispositivo conectado à internet. Foi desenvolvida em HTML, CSS e JavaScript no Visual Studio Code, com hospedagem no GitHub Pages, o qual disponibiliza o sistema por meio de um link de acesso público com integração direta ao Firebase.
A versão final é composta por duas telas principais. A primeira corresponde ao login, apresentada na figura 14, que restringe o acesso a usuários cadastrados no Firebase Authentication e exibe o status de conexão da ESP32. Após a autenticação, o usuário é direcionado à tela operacional, detalhada na figura 15.

Figura 14 – Tela inicial da interface web


Fonte: Autoria Própria (2026).

Figura 15 – Tela operacional da interface web


Fonte: Autoria Própria (2026).

A tela operacional atua como o ambiente principal da interface, funcionando como um sistema supervisório completo. A partir dela, o operador pode alternar entre os modos de operação (manual e automático), enviar comandos de acionamento (restritos ao modo manual) e ajustar a periodicidade das rotinas, definindo a unidade de tempo (minutos, horas ou dias) e o valor numérico do período. A interface também exibe dados gerais de telemetria, como a tensão das baterias de alimentação do circuito e a contagem de ciclos realizados.
Por fim, o sistema conta com uma aba dedicada ao diagnóstico e segurança da aplicação, conforme ilustra a figura 16. Nesta área, o usuário pode visualizar o histórico de alarmes e eventos do sistema, além de realizar o cadastro de novos operadores, com atualização e validação direta no banco de dados do Firebase.

Figura 16 – Histórico de alarmes, eventos e cadastro de usuários


Fonte: Autoria Própria (2026).

Maiores detalhes do projeto podem ser encontrados no repositório do Github².

### 3.7 Interface local

O objetivo de implementar uma interface física é proporcionar uma redundância no controle do sistema, assegurando a continuidade da operação mesmo em um eventual cenário de falha de conexão com a internet ou indisponibilidade da interface web.
A interface local está disposta no painel de controle e é composta por um display LCD 20x4, equipado com módulo de comunicação I2C, e dois botões de comando (um verde, para acionamento, e um vermelho, para pausa). Essa configuração oferece acesso e controle direto ao sistema de forma totalmente offline. O display atua de forma complementar, exibindo informações cruciais também presentes na interface web, como: modo de operação (manual ou automático), status de operação do sistema, tensão das baterias e contagem de ciclos realizados.
O acesso ao modo de configuração pelo display é realizado por meio de uma combinação dos comandos físicos: ao pressionar os dois botões simultaneamente por cinco segundos, o sistema entra no menu de parâmetros. Nesse modo, as funções originais dos botões são reatribuídas. O botão verde assume a função de incremento de valores e navegação para a esquerda, enquanto o botão vermelho passa a decrementar valores e navegar para a direita. Após os ajustes, a confirmação das configurações inseridas é feita pressionando novamente ambos os botões de forma simultânea por dois segundos.

### 3.8 Custos do protótipo

A viabilidade do projeto envolveu o levantamento dos custos de fabricação do protótipo, categorizados por área de desenvolvimento. A tabela 1 detalha os componentes mecânicos utilizados para a montagem do limpador horizontal, os quais garantem a sustentação da escova, movimentação do equipamento e abriga os componentes de controle do sistema. Cabe ressaltar que determinados materiais foram fornecidos pela Faculdade Engenheiro Salvador Arena (FESA) e, portanto, estão indicados com um asterisco (*) na coluna de preço total das tabelas a seguir.

² Todas as documentações sobre o projeto, como projeto mecânico, circuito elétrico e programação, estão disponíveis em: https://github.com/rubexdev/tcc-sistema-automacao-limpeza-solar-fesa

Tabela 1 – Custos da estrutura mecânica do protótipo
Material | Qtde. | Preço Total
Acoplamento 8x12mm – motores | 2 | R$96,00
Chapa de fixação do motor da escova | | *
Chapa de fixação dos motores de
deslocamento | | *
Chapa de fixação – suporte do
limpador | 2 | *
Escova de limpeza | 1 | R$680,00
Eixo para as rodas | 8 | *
Mancal com rolamento | 2 | R$61,83
Motor de deslocamento | 2 | R$513,00
Motor da escova | 1 | R$360,00
Painel de controle | 1 | R$78,90
Painel de comando | 1 | R$72,59
Placa acrílica para o painel de
comando | 1 | *
Rodas 4" | 8 | R$130,00
Suporte das rodas horizontais | 4 | R$80,00
Suporte das rodas verticais | 4 | R$120,00
Tubo 30x30x3 – suporte do limpador | 2 | R$120,00
TOTAL | | R$2.312,32
Fonte: Autoria Própria (2026).

Para assegurar o funcionamento da estrutura mecânica, foram integrados os componentes eletrônicos responsáveis pelo processamento, controle e alimentação do sistema. A tabela 2 apresenta a relação e os custos atrelados a esses dispositivos.

Tabela 2 – Custos dos componentes elétricos do protótipo
Material | Qtde. | Preço Total
Botões de comando 24 V | 2 | *
Controlador de carga solar 30A 12/24 | 1 | R$ 39,90
Conversor boost 12V – 24V | 1 | R$ 54,61
Conversor buck 12V – 5V | 1 | R$ 20,30
Disjuntor bipolar (20A) | 1 | *
Display LCD 20x4 | 1 | R$ 38,70
Drivers BTS7960 (ponte H) | 3 | R$ 135,00
ESP32-WROOM32 | 1 | R$ 90,04
Módulos bidirecionais | 2 | R$20,30

Material | Qtde. | Preço Total
Optoacoplador de 8 canais PC817 | 1 | R$51,00
Placa para soldagem | 1 | R$20,90
Prensa-cabo | 5 | R$16,50
Sensores de tensão | 2 | R$35,97
Sensores ultrassônicos | 2 | *
Ventoinha | 1 | R$20,80
TOTAL | R$544,02
Fonte: Autoria Própria (2026).

Além da eletrônica e da mecânica embarcadas no limpador, fez-se necessária a estruturação de um ambiente para a validação prática do projeto. A tabela 3 discrimina os custos gerais de infraestrutura, que contemplam a aquisição de um painel solar de 36 células, bem como os perfis e estruturas de madeira para a fixação do módulo fotovoltaico e dos trilhos de deslocamento.

Tabela 3 – Custos gerais do projeto
Material | Qtde. | Preço Total
Madeiras para estrutura de suportação da placa solar | 12 | R$275,00
Parafusos, roscas e arruelas | Diversos | R$150,00
Perfis de aço para trilhos do limpador | 6 | R$120,00
Placa solar – 36 células, 1x1m | 1 | R$340,00
TOTAL | R$885,00
Fonte: Autoria Própria (2026).

Dessa forma, para a construção do protótipo e implementação do sistema descrito, os custos totais estão apresentados na Tabela 4.

Tabela 4 – Custos do protótipo
Material | Preço Total
Custos dos componentes mecânicos do protótipo | R$2312,32
Custos dos componentes elétricos do protótipo | R$544,02
Custos gerais do projeto | R$855,00
TOTAL | R$3.711,02
Fonte: Autoria Própria (2026).

### 4 Resultados e discussões

A avaliação do protótipo foi dividida em duas etapas complementares, com o objetivo de analisar tanto a eficiência mecânica do processo quanto os impactos da remoção de sujeira no desempenho energético do sistema. A partir dos testes e resultados, foi possível analisar a performance do protótipo construído e avaliar os possíveis modos de falha do sistema.

### 4.1 Metodologias de avaliação e resultados práticos

A primeira metodologia consistiu na avaliação da capacidade de remoção de partículas por meio de um ensaio controlado, baseado na simulação de sujidade sobre a superfície do painel fotovoltaico. Para isso, utilizou-se farinha de trigo, material de granulometria fina escolhido por sua capacidade de mimetizar o acúmulo de poeira em condições reais de operação, além de oferecer alto contraste visual na superfície da placa. Inicialmente, uma massa conhecida de 200 g do material foi distribuída de maneira uniforme sobre o painel. Em seguida, o sistema de limpeza foi acionado, realizando ciclos completos de operação, definidos pelo deslocamento lateral do protótipo com a escova rotacionando tangente à superfície. Ao final do ciclo, a quantidade de material residual foi coletada e pesada em uma balança de precisão.
Para garantir a robustez e a confiabilidade dos dados, o experimento foi repetido quatro vezes, variando a quantidade de ciclos de varredura (ida e volta) realizados pela escova. A eficiência de limpeza (η) foi determinada pela relação entre a massa removida e a massa total aplicada, conforme a equação 1:

η =

mremovida

maplicada

× 100 | (1)

As Figuras 17(a) e 17(b) ilustram os ensaios práticos de remoção de partículas sobre a superfície do painel fotovoltaico durante esta primeira etapa de validação.

Figura 12 – Placa solar antes do ensaio 17(a) e placa solar após a limpeza automático 17(b)


Fonte: Autoria Própria (2026).

Os dados quantitativos obtidos nesses ensaios estão consolidados na tabela 5, que detalha a massa de farinha aplicada, o número de ciclos executados, a massa residual não removida, a massa efetivamente removida e a eficiência calculada.

Tabela 5 – Resultados obtidos nos testes de capacidade de remoção de partículas
Teste | Massa aplicada
| (g) | Nº de ciclos | Massa residual
| | | (g) | Massa removida
| | | | (g) | Eficiência
| | | | | (%)
1 | 200 | 1 | 18 | 182 | 91,0%
2 | 200 | 1 | 16 | 184 | 92,0%
3 | 200 | 2 | 8 | 192 | 96,0%
4 | 200 | 2 | 6 | 194 | 97,0%
Fonte: Autoria Própria (2026).

A análise dos dados da tabela 5 evidencia a relação direta entre o tempo de atuação do sistema e a sua eficácia. Nos testes 1 e 2, submetidos a apenas um ciclo de limpeza, a eficiência média ficou em 91,5%. Já nos testes 3 e 4, a aplicação de um segundo ciclo de varredura, que é a ideia de funcionamento principal, reduziu significativamente a massa residual, elevando a eficiência para o patamar de 96,5%. No geral, o sistema apresentou uma eficiência média global de 94,0% na remoção de partículas. Observou-se ainda que o volume residual de sujidade não removida se concentrou majoritariamente nas extremidades estruturais do painel, indicando o limite de alcance mecânico das cerdas da escova, ao passo que toda a área útil central de captação luminosa foi devidamente desobstruída.
A segunda metodologia avaliou o impacto da sujidade na eficiência de geração elétrica. O sistema foi analisado em dois cenários distintos sob as mesmas condições de irradiação solar: com a placa propositalmente suja e com a superfície limpa pelo sistema automatizado. Em ambos os cenários, o painel fotovoltaico foi conectado a uma bateria de motocicletas, utilizando o controlador de carga para assegurar os níveis adequados de tensão. O ensaio consistiu no monitoramento do processo de carregamento durante um período de 3 horas. A avaliação de desempenho energético foi conduzida por meio da medição direta da tensão nos terminais da bateria e da tensão de saída do painel. Dessa forma, comparou-se a curva de elevação da carga (variação de tensão) em ambas as condições, evidenciando as perdas de captação energética causadas pela obstrução na superfície.
A tabela 6 apresenta os resultados do monitoramento de tensão da bateria de 12 V após os períodos de carregamento. Para garantir o rigor comparativo, a tensão inicial da bateria foi descarregada para o mesmo patamar antes do início de cada ciclo. Observou-se ainda que o volume residual de sujidade não removida se concentrou majoritariamente nas extremidades estruturais do painel, indicando o limite de alcance mecânico das cerdas da escova, ao passo que toda a área útil central de captação luminosa foi devidamente desobstruída.

Tabela 6 – Resultados obtidos nos testes de carregamento de carga

Teste | Cenário
| | | Tensão
| | | inicial
(V)

Tensão final
(V)

Ganho de
tensão (ΔV)
1 | Placa suja (com farinha) | 11,8 | 12,1 | +0,3 V
2 | Placa limpa (após ciclo) | 11,8 | 12,6 | +0,8 V
3 | Placa suja (com farinha) | 11,7 | 12,0 | +0,3 V
4 | Placa limpa (após ciclo) | 11,7 | 12,4 | +0,7 V
Fonte: Autoria Própria (2026).

Os dados da tabela 6 comprovam a eficácia operacional do projeto. Observa-se que, com a placa obstruída, a taxa de conversão energética foi severamente prejudicada, resultando em um ganho de tensão de apenas 0,3 V no período amostral. Por outro lado, após o acionamento do limpador automatizado, a desobstrução da área de captação permitiu que a placa operasse mais próxima à sua eficiência nominal, refletindo em um ganho de tensão consideravelmente maior (com média de 0,75 V) no mesmo intervalo de tempo de exposição solar.
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

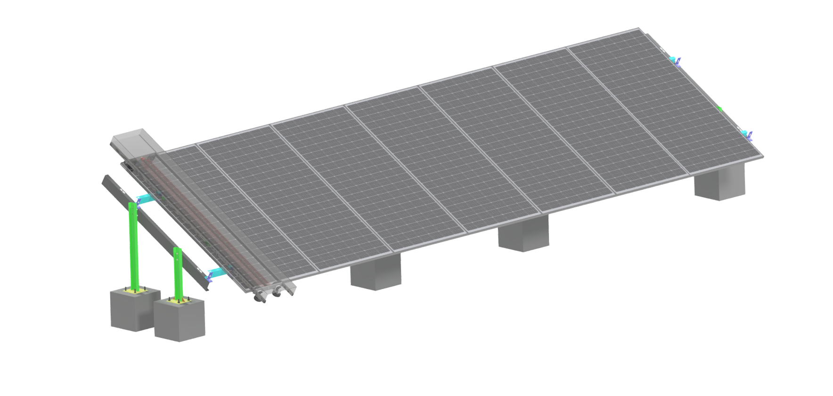
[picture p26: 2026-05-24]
mecanica/Modelagem/Main_Solar_Structure/Estrutura Principal.bmp

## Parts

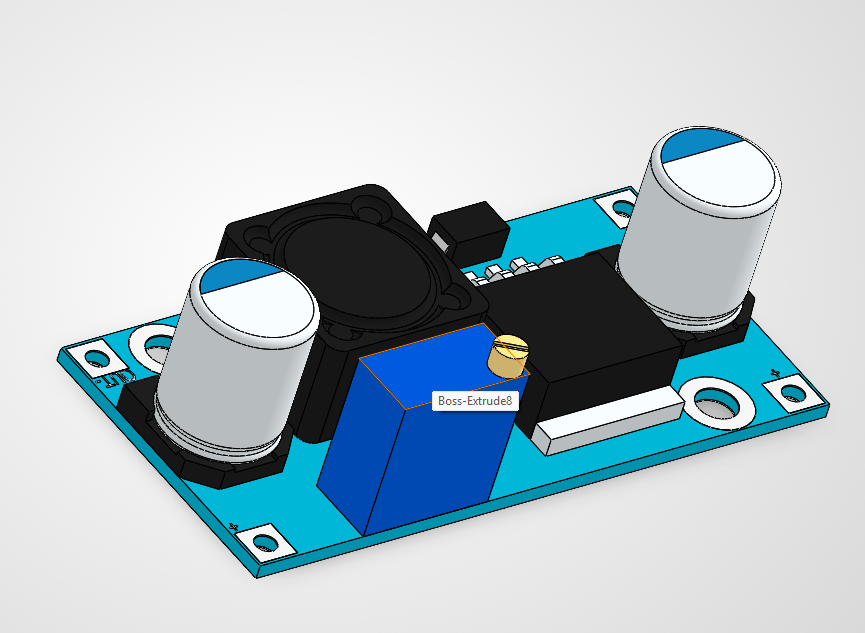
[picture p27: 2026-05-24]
mecanica/Componentes/dc-dc-3a-1.snapshot.5/dc-dc-3a-1.snapshot.5/Знімок екрана 2026-03-12 102432.png

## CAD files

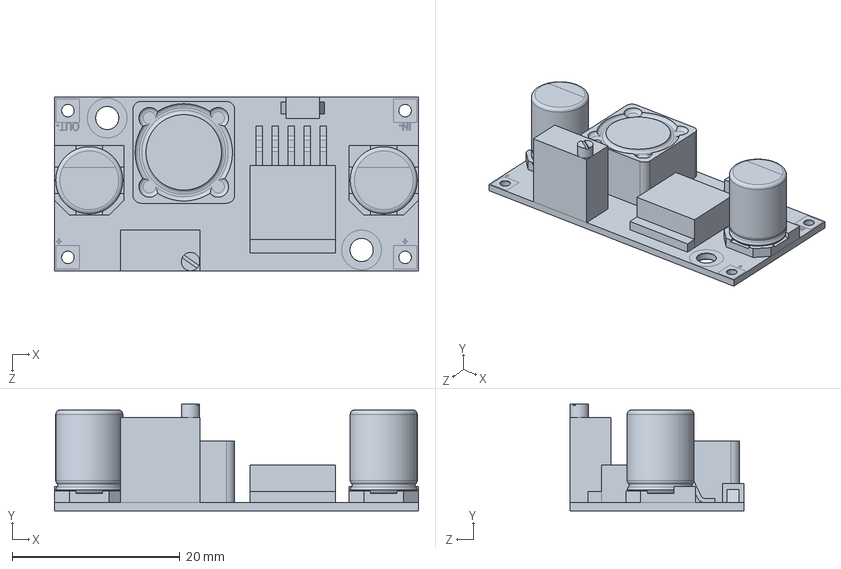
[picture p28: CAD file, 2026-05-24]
mecanica/Componentes/dc-dc-3a-1.snapshot.5/dc-dc-3a-1.snapshot.5/DC-DC 3A.SLDPRT
43.4 x 12.8 x 20.7 mm

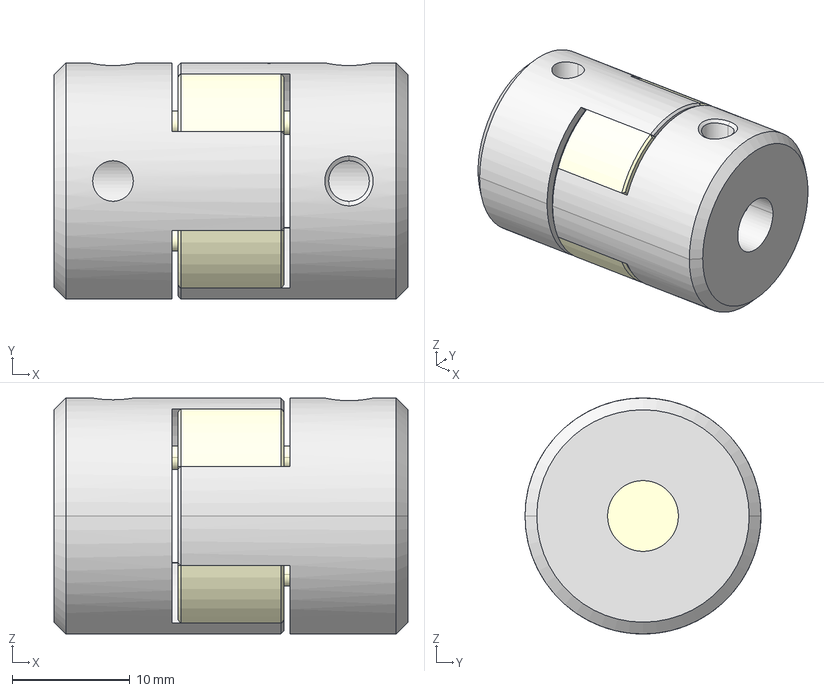
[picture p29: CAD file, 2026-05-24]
mecanica/Componentes/jlcmc-shaft-couplings-jaw-coupling-spider-type-elastomer-coupling-1.snapshot.1/CXHJ-D-D20-d5-e6.step
30.0 x 20.0 x 20.0 mm
����1^1745913842610_CXHJ-D
���ڻ�^1745913842610
����2^1745913842610_CXHJ-D

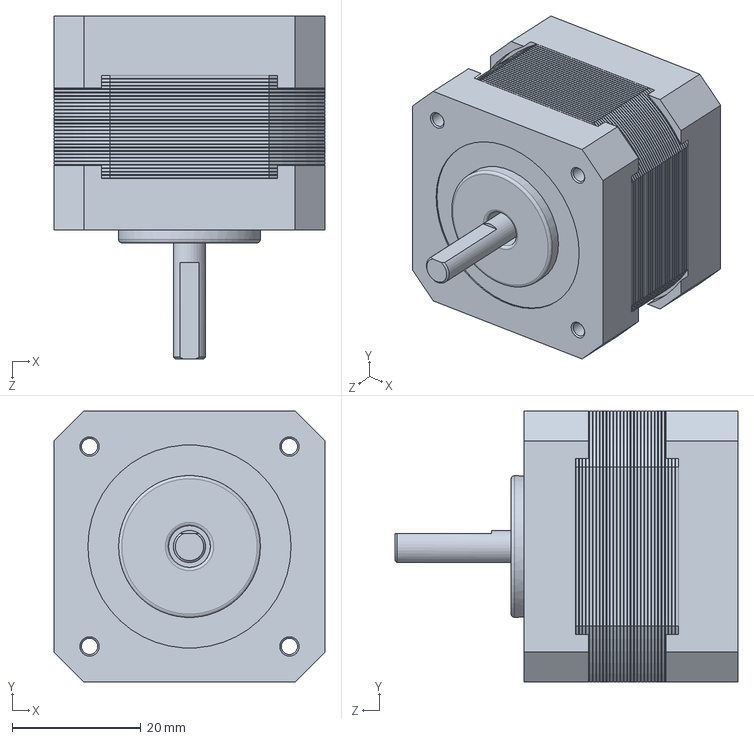
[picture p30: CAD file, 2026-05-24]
mecanica/Modelagem/Main_Solar_Structure/NEMA 17HS13-0404S1.SLDPRT
42.0 x 42.0 x 53.2 mm

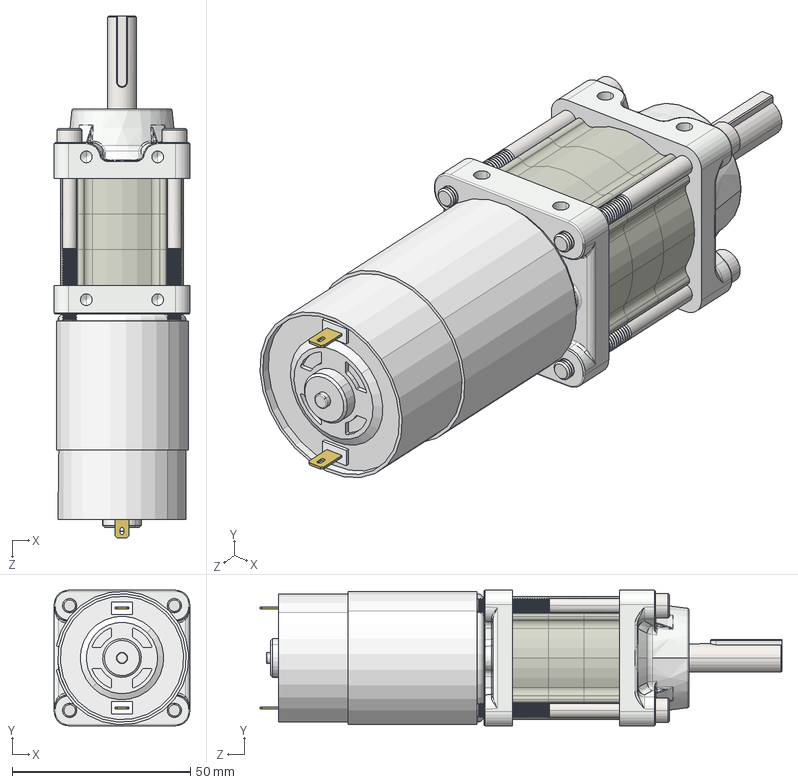
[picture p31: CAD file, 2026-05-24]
mecanica/Modelagem/Projeto Limpador/Orbit500-V2.0-64X-Motor555-Step.STEP
38.0 x 38.0 x 146.3 mm

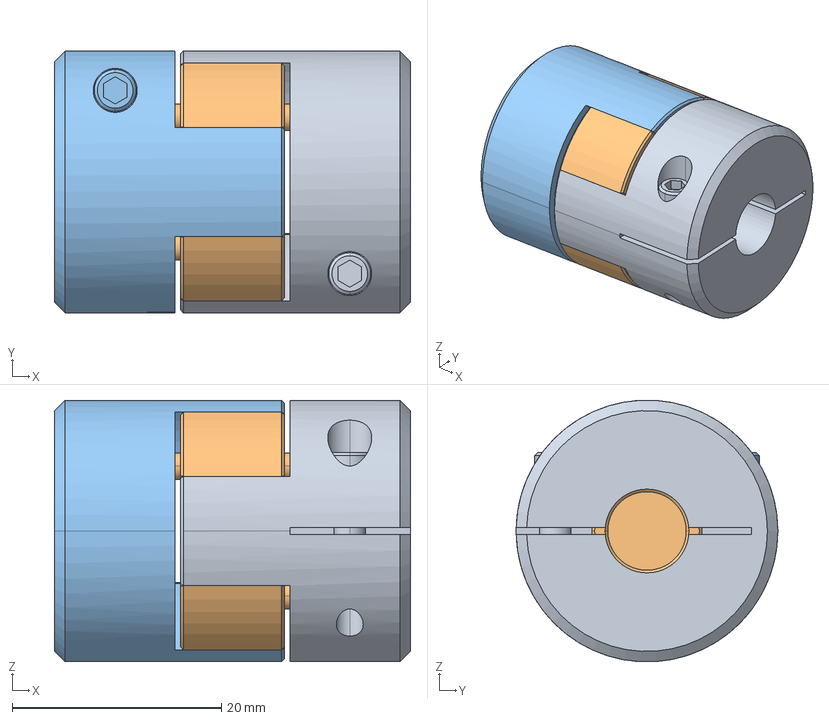
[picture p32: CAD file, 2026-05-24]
mecanica/Componentes/jlcmc-shaft-couplings-jaw-coupling-spider-type-elastomer-coupling-1.snapshot.1/CXHG-C-D25-d5-e8.step
34.0 x 25.0 x 25.0 mm
����1^1752130758416_CXHG-C
���ڻ�^1752130758416
����2^1752130758416_CXHG-C

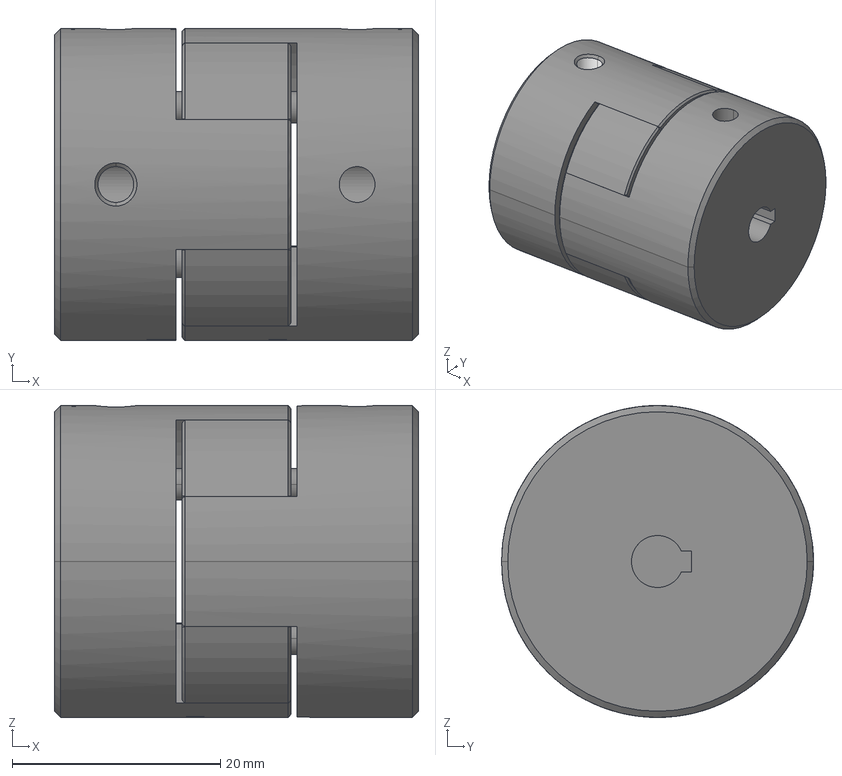
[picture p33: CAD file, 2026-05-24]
mecanica/Componentes/jlcmc-shaft-couplings-jaw-coupling-spider-type-elastomer-coupling-1.snapshot.1/CXHN-D30-d5-e5.step
35.0 x 30.0 x 30.0 mm
����1^1756457206259
���ڻ�^1756457206259
����2^1756457206259

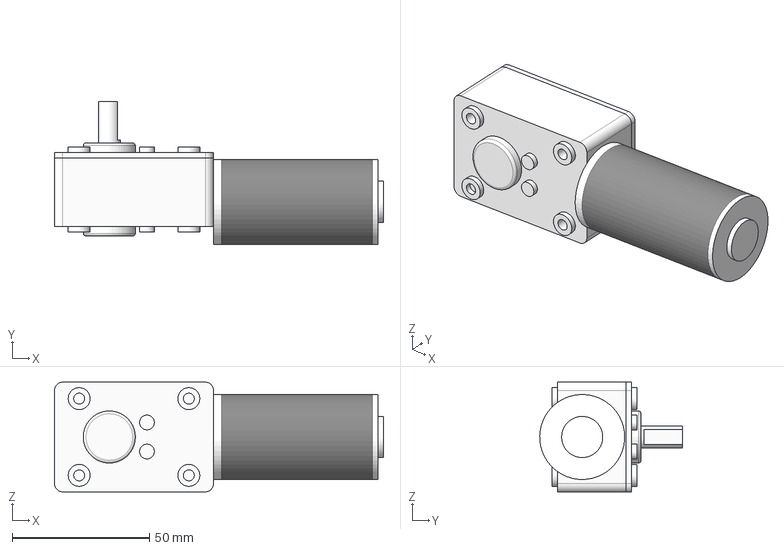
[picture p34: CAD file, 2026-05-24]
mecanica/Modelagem/Projeto Limpador/Worm_Gear_Motor_12V.stp
120.0 x 52.0 x 40.0 mm

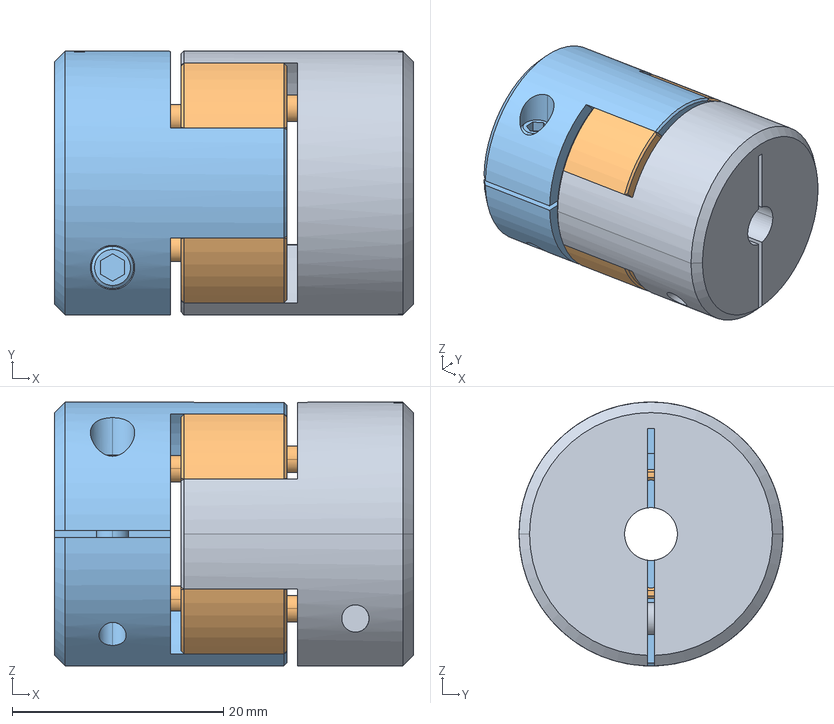
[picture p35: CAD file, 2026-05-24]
mecanica/Componentes/jlcmc-shaft-couplings-jaw-coupling-spider-type-elastomer-coupling-1.snapshot.1/CXHH-D25-d5-e5.step
34.0 x 25.0 x 25.0 mm
����1^2026943761522855936
���ڻ�^2026943761522855936
����2^2026943761522855936

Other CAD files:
mecanica/Modelagem/Main_Solar_Structure/Desenhos/Suporte L.dwg
mecanica/Modelagem/Main_Solar_Structure/DWG/Perfil U - Lateral.dwg
mecanica/Modelagem/Main_Solar_Structure/Só a estrutura/Limpador.dwg
mecanica/Modelagem/PDFS/Suporte _ Motores.dwg
mecanica/Modelagem/Main_Solar_Structure/DWG/Fixador.dwg
mecanica/Modelagem/Main_Solar_Structure/Só a estrutura/Estrutura completa.dwg
mecanica/Modelagem/Projeto Limpador/Suporte _ Motores.dwg
mecanica/Modelagem/Main_Solar_Structure/DWG/Coluna menor.dwg
mecanica/Modelagem/Main_Solar_Structure/Só a estrutura/Limpador Explodido.dwg
mecanica/Modelagem/Main_Solar_Structure/DWG/Coluna maior.dwg
mecanica/Componentes/Chapa para sensor ultrassônico.ipt
mecanica/Componentes/Proteção de acrilico-Painel de controle.ipt
mecanica/Componentes/Proteção de acrilico.ipt
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

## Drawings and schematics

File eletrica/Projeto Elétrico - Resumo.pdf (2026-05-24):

1

3 | 6 | 8 7 | 9

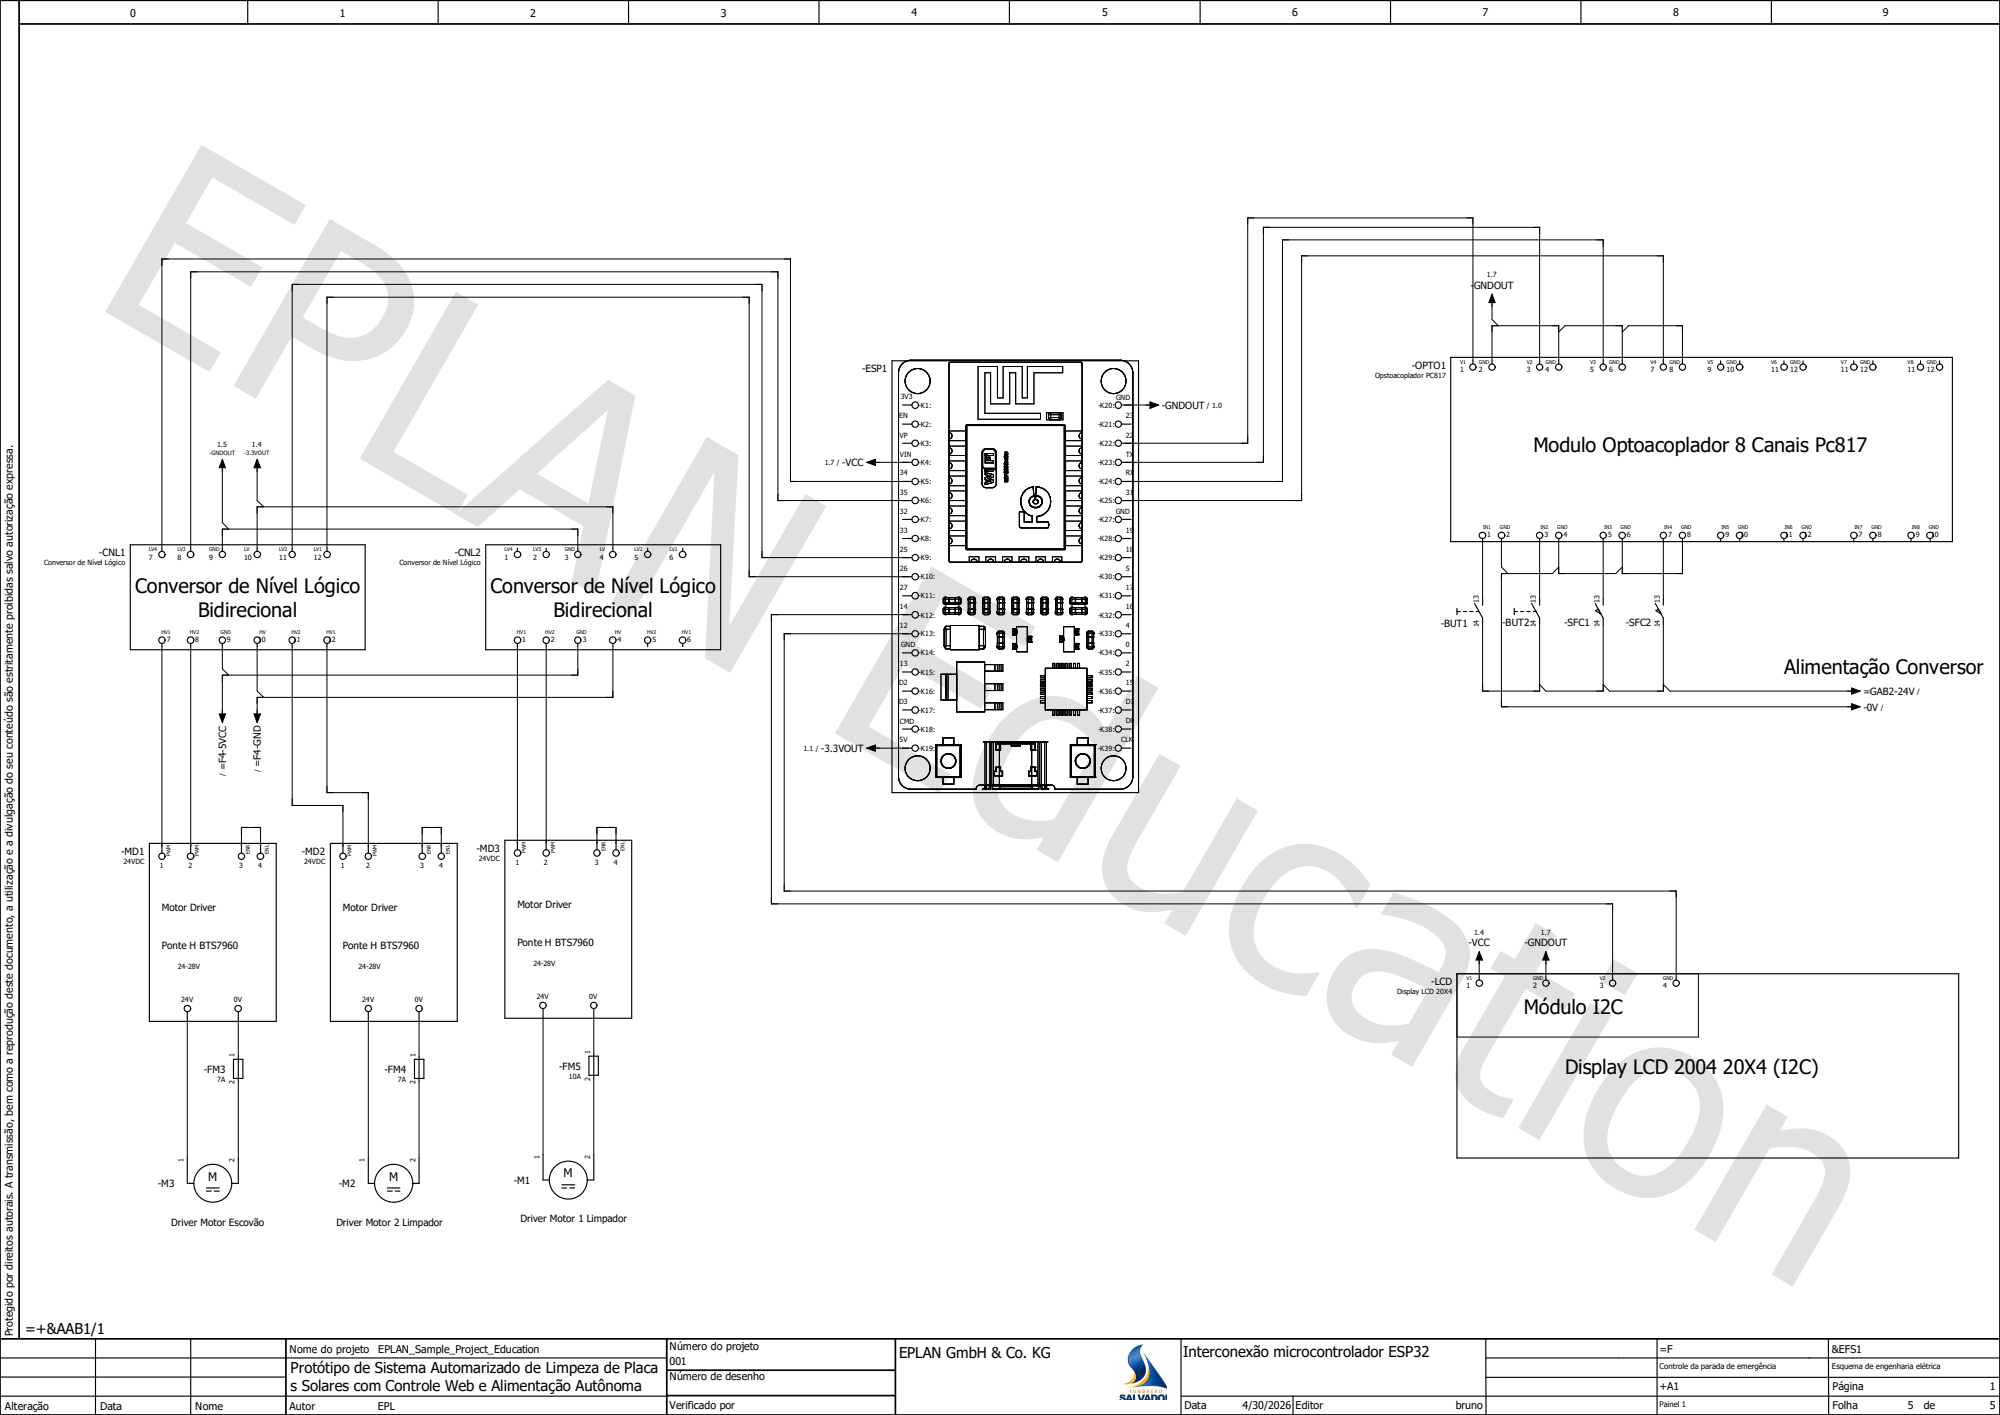
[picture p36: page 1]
=+&AAB1/1; Autor; EPL Protegido por direitos autorais. A transmissão, bem como a reprodução deste documento, a utilização e a divulgação do seu conteúdo são estritamente proibidas salvo autorização expressa.; -ESP1; VIN; GND; CMD; CLK; Modulo Optoacoplador 8 Canais Pc817; Display LCD 2004 20X4 (I2C); Módulo I2C; Driver Motor Escovão; Driver Motor 2 Limpador; Driver Motor 1 Limpador; -CNL2; Conversor de Nível Lógico; -CNL1; -MD3 24VDC; Motor Driver; Ponte H BTS7960; 24-28V PWM; 0V PWM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

HV Conversor de Nível Lógico
Bidirecional

Conversor de Nível Lógico

Nome do projeto EPLAN_Sample_Project_Education | Número do projeto 001 | EPLAN GmbH & Co. KG | | | =F Interconexão microcontrolador ESP32 | &EFS1
Protótipo de Sistema Automarizado de Limpeza de Placa s Solares com Controle Web e Alimentação Autônoma | | | | | Controle da parada de emergência | Esquema de engenharia elétrica

Número de desenho

+A1 | Página 1

Alteração | Data | Nome | | Verificado por | | Data 4/30/2026 | Editor bruno | | Painel 1 | Folha 5 de 5

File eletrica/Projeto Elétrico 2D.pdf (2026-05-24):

-DS1

-2L1 / 2.0

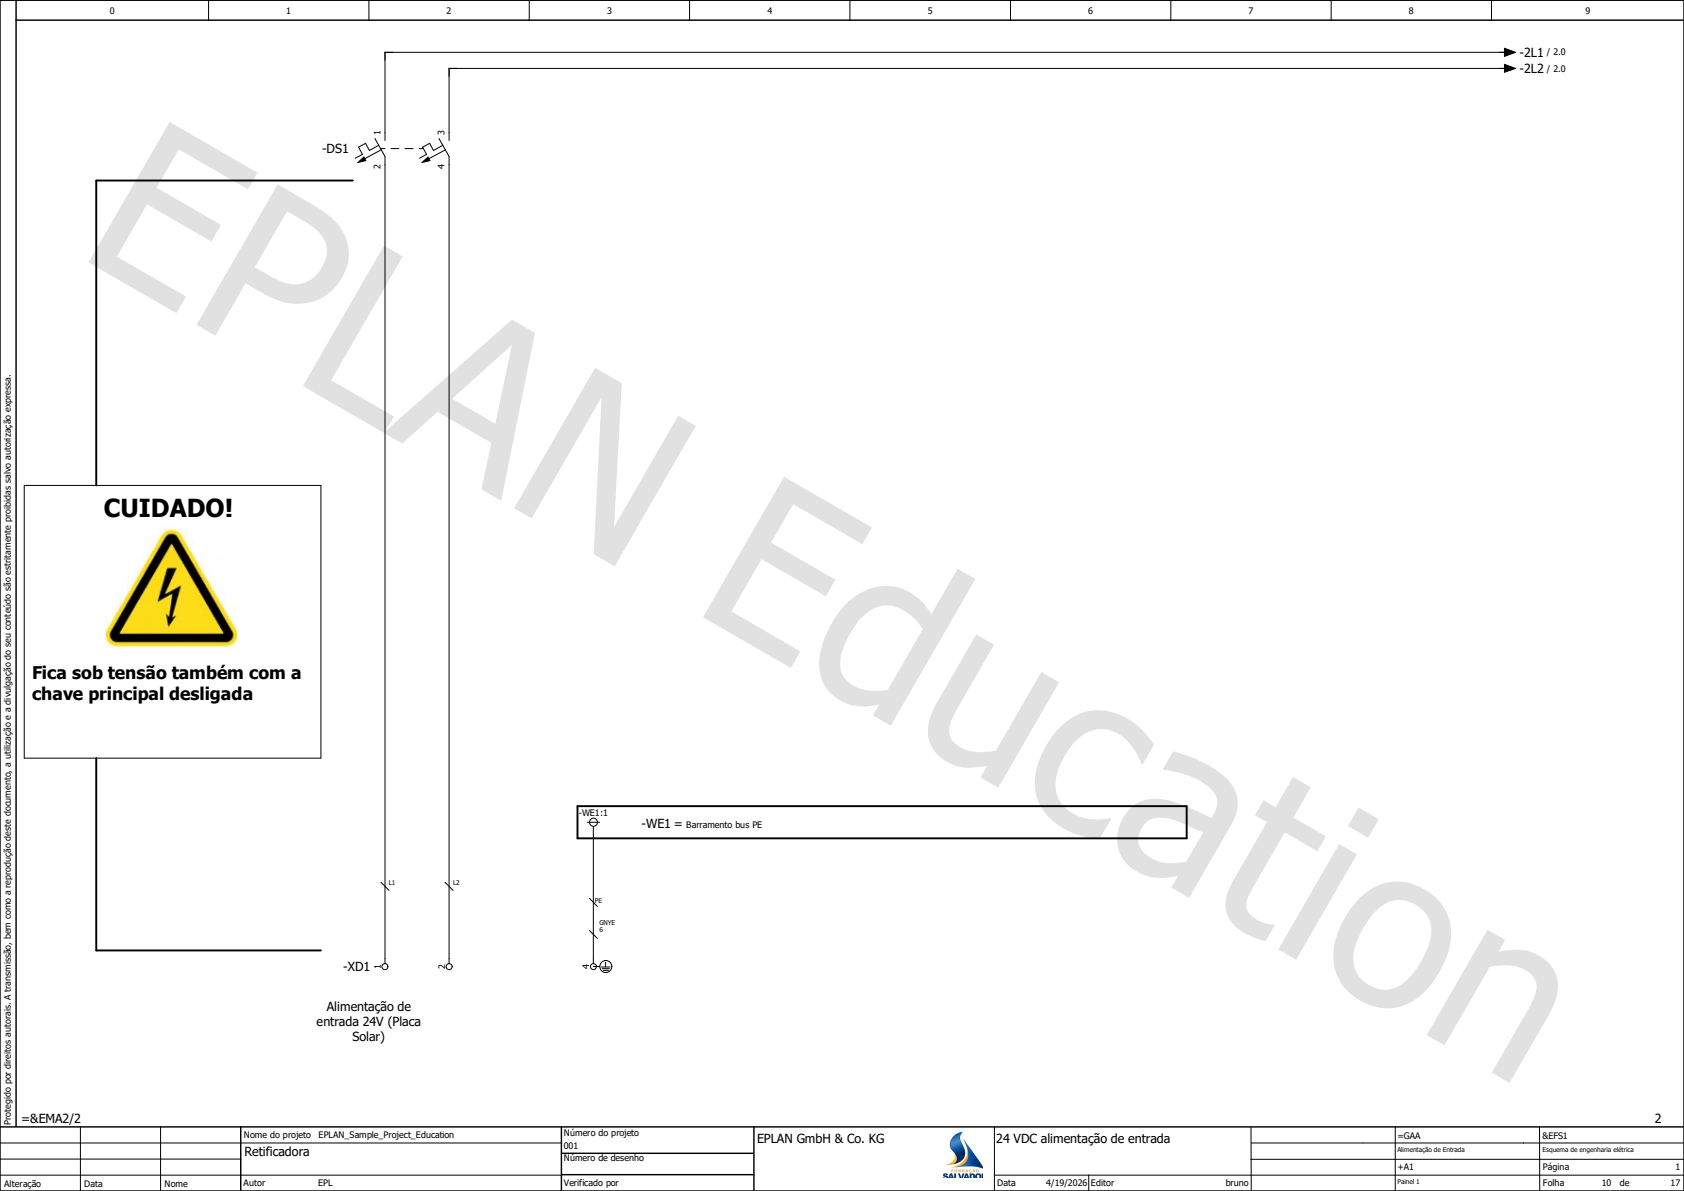
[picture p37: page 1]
=&EMA2/2; Autor; EPL Protegido por direitos autorais. A transmissão, bem como a reprodução deste documento, a utilização e a divulgação do seu conteúdo são estritamente proibidas salvo autorização expressa.; CUIDADO!; Alimentação de entrada 24V (Placa Solar); GNYE

Fica sob tensão também com a
chave principal desligada

-WE1 = Barramento bus PE

Nome do projeto EPLAN_Sample_Project_Education | Número do projeto 001 | EPLAN GmbH & Co. KG | | | =GAA 24 VDC alimentação de entrada | &EFS1
Retificadora | | | | | Alimentação de Entrada | Esquema de engenharia elétrica

Número de desenho

+A1 | Página

Alteração | Data | Nome | | Verificado por | | Data 4/19/2026 | Editor bruno | | Painel 1 | Folha 10 de 17

1.9 / -2L1 | =GAA-2L1 /
1.9 / -2L2 | =GAA-2L2 / 0V / =GAB2/1.0 12V / =GAB2/1.0

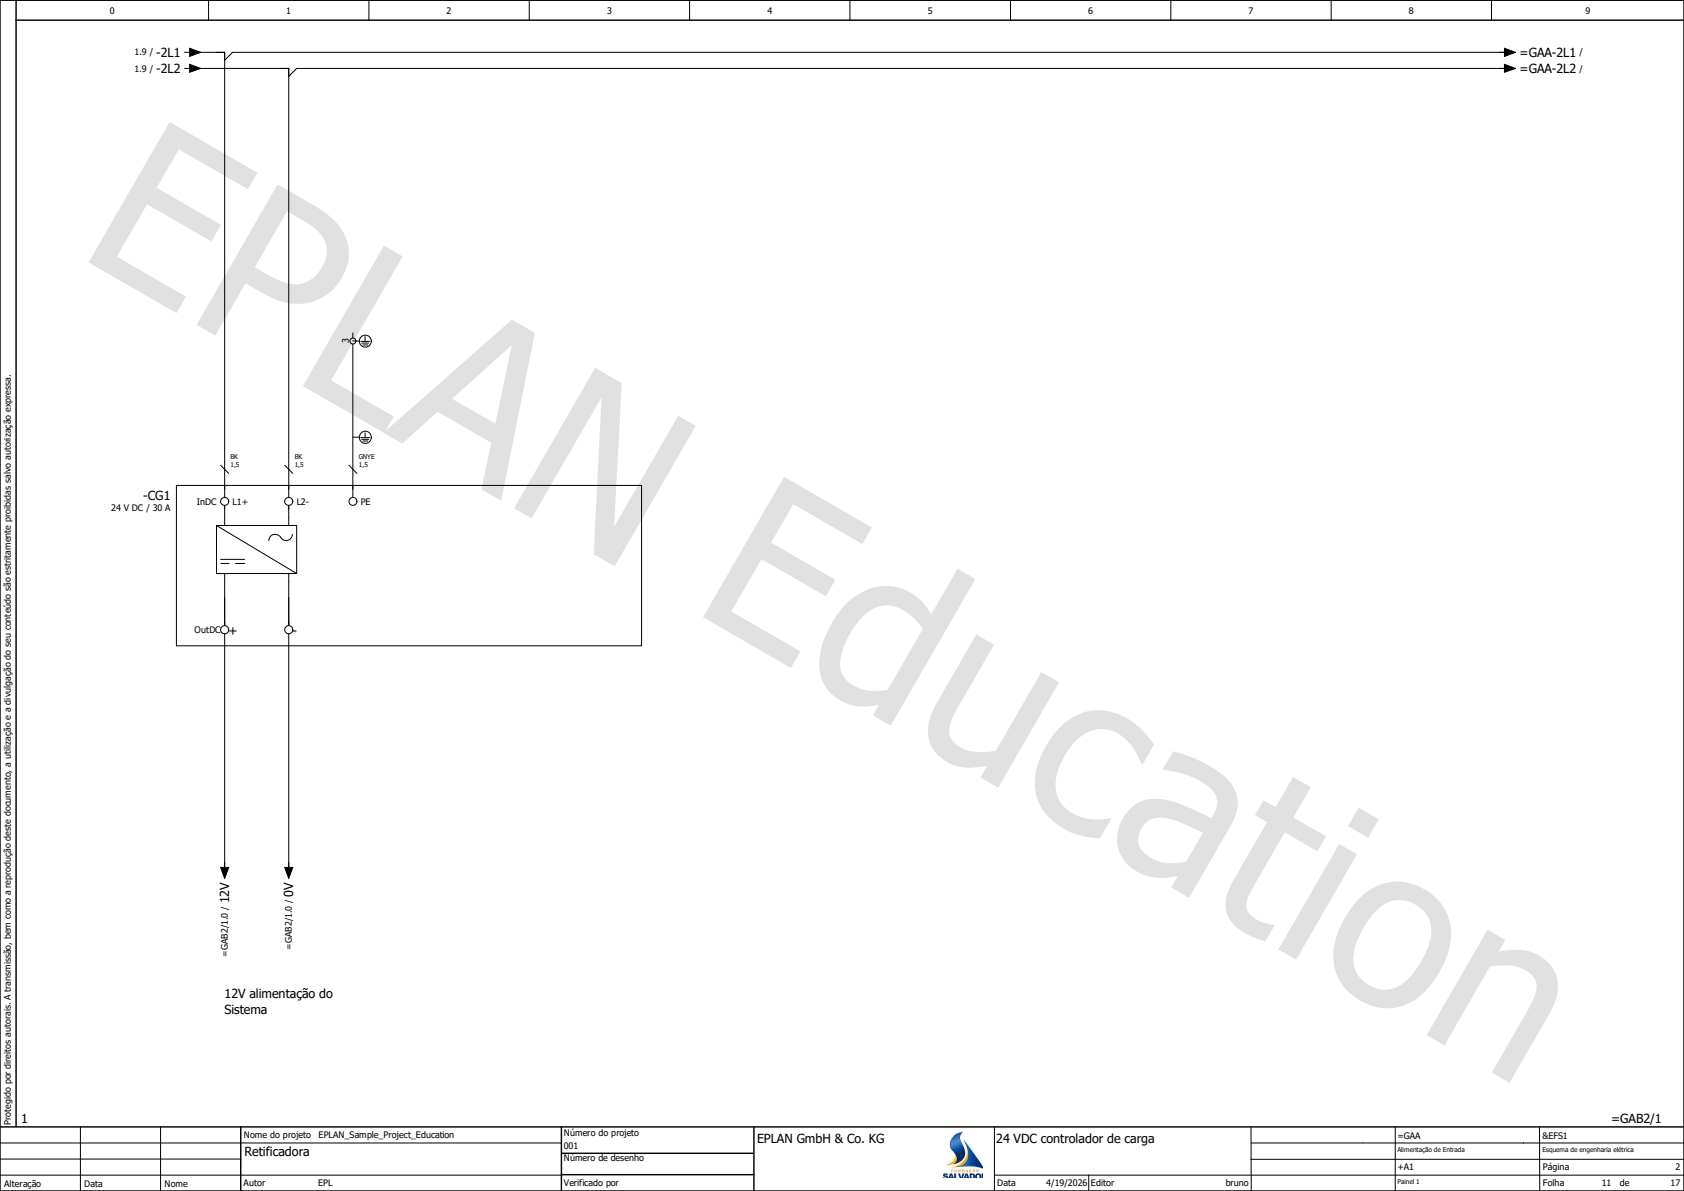
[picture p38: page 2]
=GAB2/1; Autor; EPL Protegido por direitos autorais. A transmissão, bem como a reprodução deste documento, a utilização e a divulgação do seu conteúdo são estritamente proibidas salvo autorização expressa.; OutDC +; InDC; 12V alimentação do Sistema; GNYE

=GAA 24 VDC controlador de carga

Alimentação de Entrada | Esquema de engenharia elétrica

-BT1

-BT2

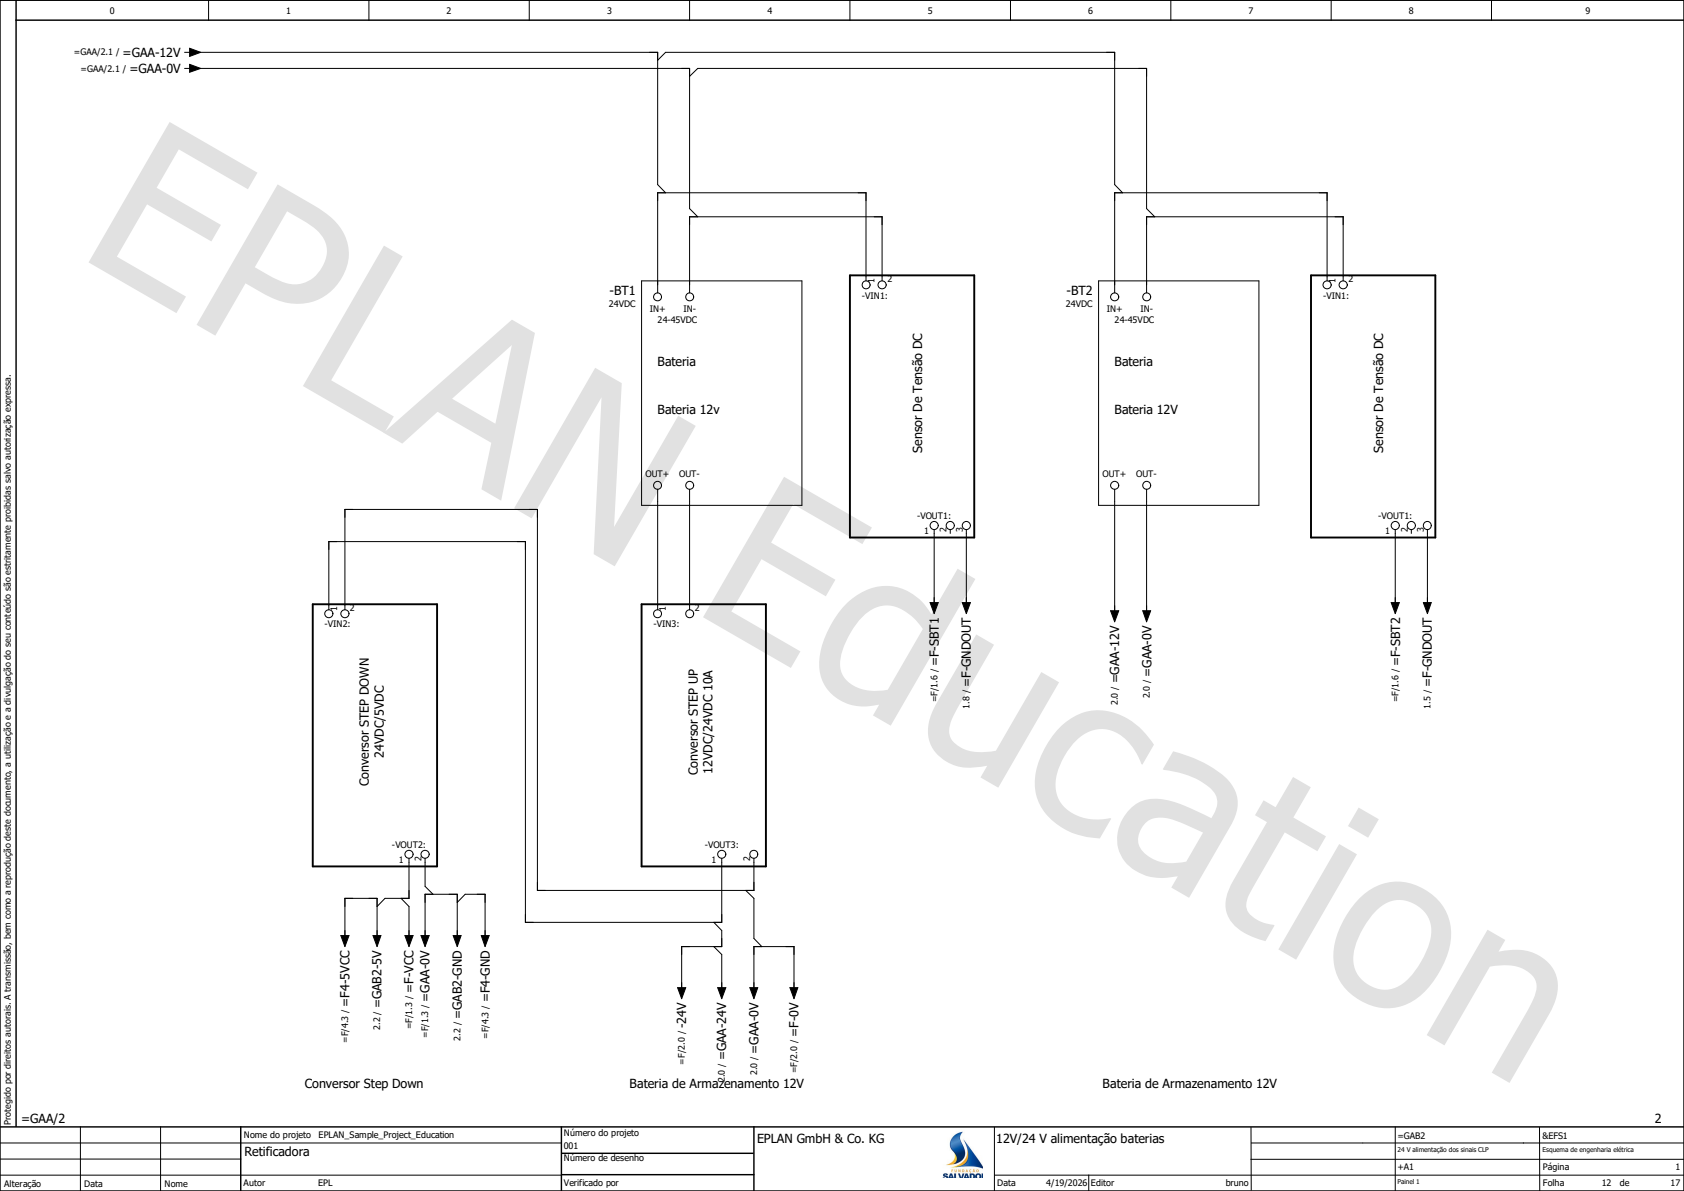
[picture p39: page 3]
=GAA/2; Autor; EPL Protegido por direitos autorais. A transmissão, bem como a reprodução deste documento, a utilização e a divulgação do seu conteúdo são estritamente proibidas salvo autorização expressa.; Conversor STEP DOWN 24VDC/5VDC; -VIN2: ¹; -VOUT2: 1 2; 24VDC; 24-45VDC; Bateria; Bateria 12v; Bateria 12V; Conversor Step Down; Bateria de Armazenamento 12V Conversor STEP UP 12VDC/24VDC 10A; -VIN3: ¹; -VOUT3:; Sensor De Tensão DC; -VIN1: ¹; -VOUT1:; -VOUT1: 1 2; OUT+ OUT-; OUT+ OUT- 3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

Bateria de Armazenamento 12V

=GAB2 12V/24 V alimentação baterias

24 V alimentação dos sinais CLP | Esquema de engenharia elétrica

## 1.4 / =GAA-24V 1.4 / =GAA-0V

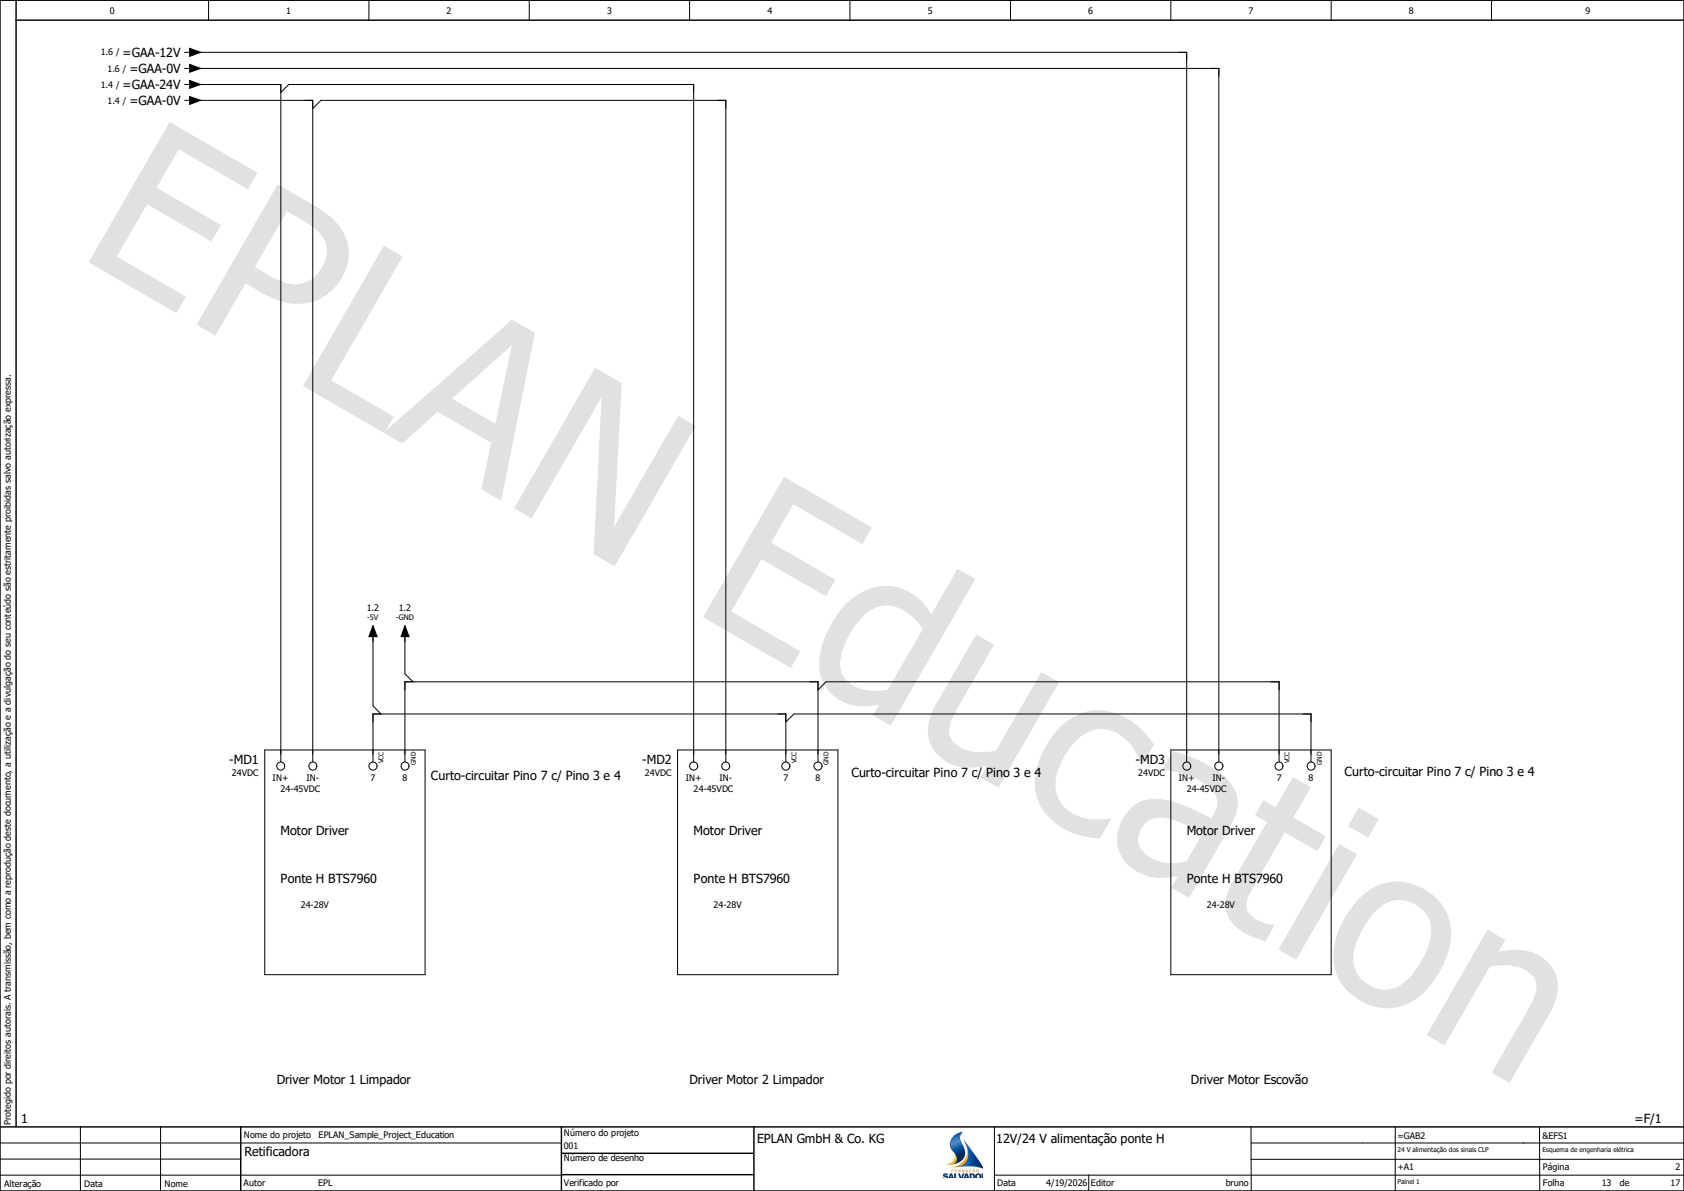
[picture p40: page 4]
Autor; EPL Protegido por direitos autorais. A transmissão, bem como a reprodução deste documento, a utilização e a divulgação do seu conteúdo são estritamente proibidas salvo autorização expressa.; 24VDC; 24-45VDC; Motor Driver; Ponte H BTS7960; -MD2 24VDC; -MD3 24VDC; Curto-circuitar Pino 7 c/ Pino 3 e 4; Curto-circuitar Pino 7 c/ Pino 3 e 4 GND; 8 VCC; 7 VCC 7 GND; 8 VCC 7 GND; 1.6 / =GAA-12V 1.6 / =GAA-0V; -GND

Driver Motor 1 Limpador

Driver Motor 2 Limpador

Driver Motor Escovão

=GAB2 12V/24 V alimentação ponte H

24 V alimentação dos sinais CLP | Esquema de engenharia elétrica

## -ESP1

# Ligar Antenna

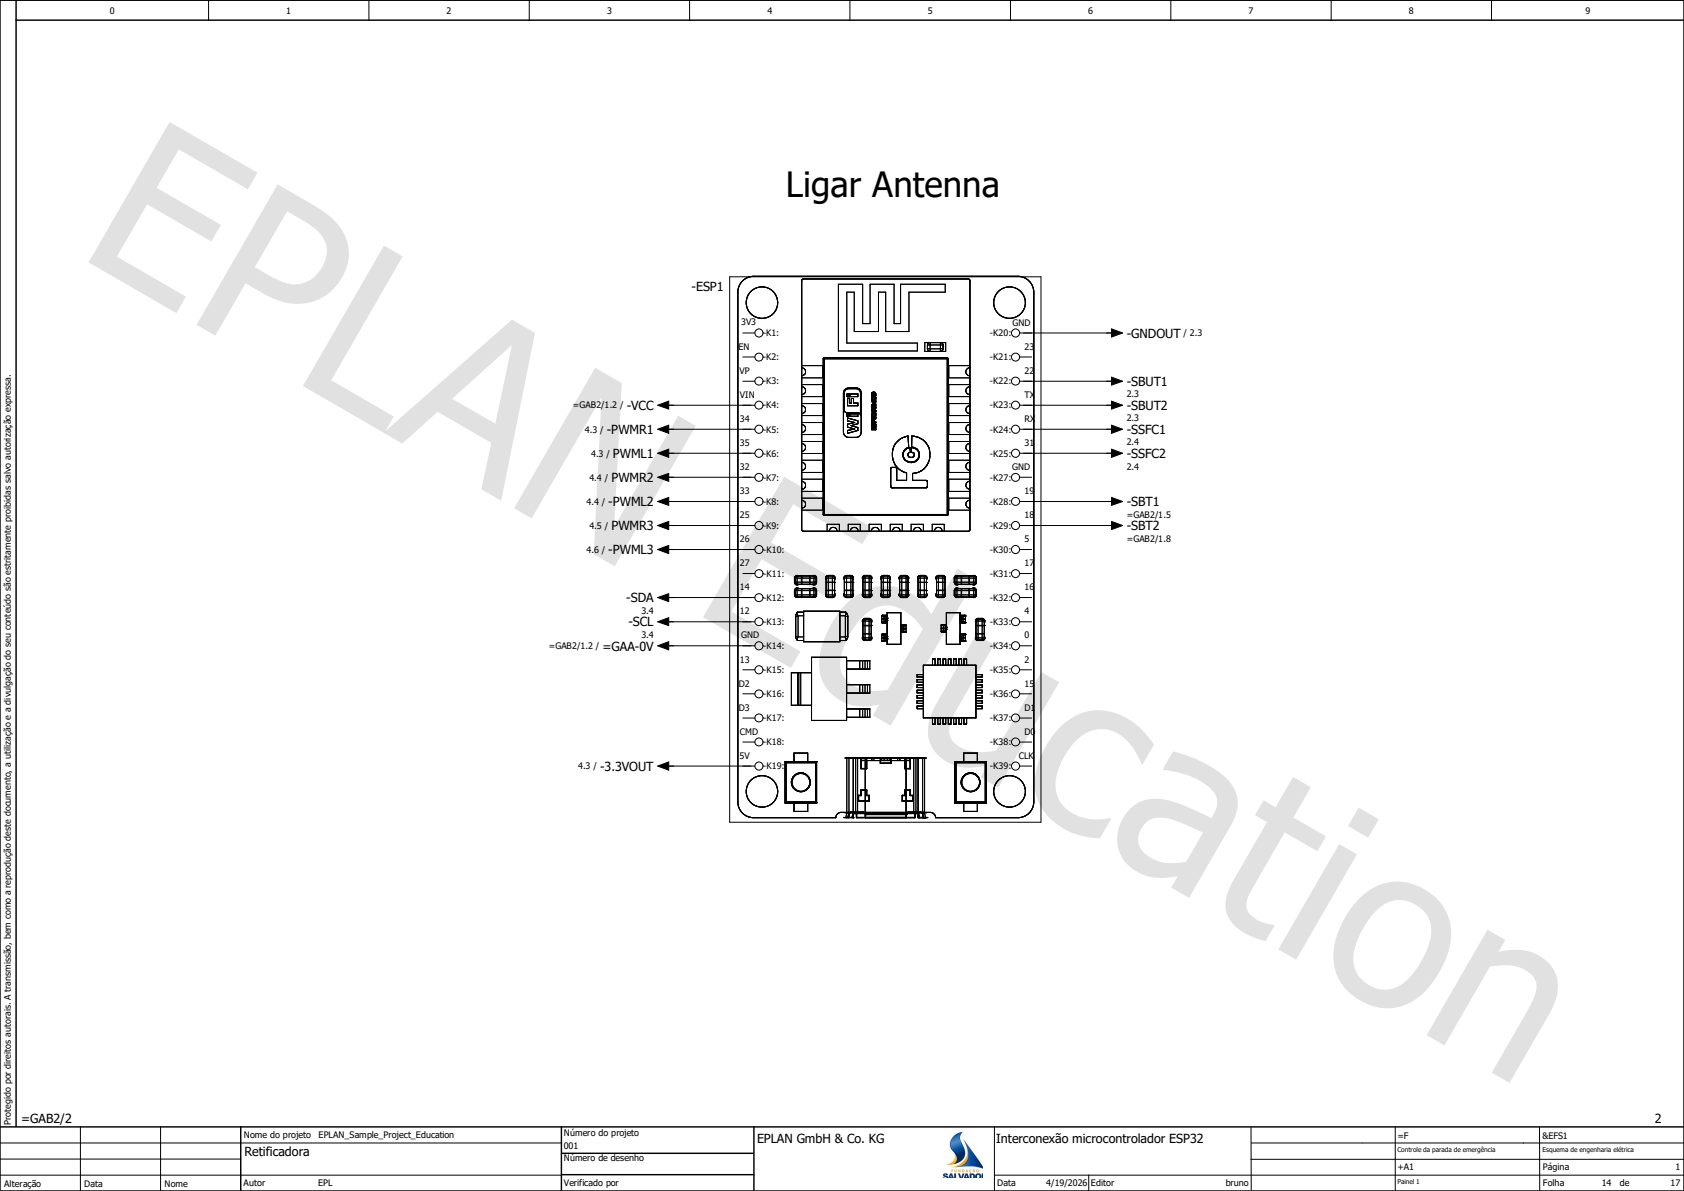
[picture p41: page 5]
=GAB2/2; Autor; EPL Protegido por direitos autorais. A transmissão, bem como a reprodução deste documento, a utilização e a divulgação do seu conteúdo são estritamente proibidas salvo autorização expressa.; VIN; GND; CMD; CLK; =GAB2/1.2 / -VCC; =GAB2/1.2 / =GAA-0V; -GNDOUT / 2.3; 4.3 / -3.3VOUT; -SBUT1 2.3 -SBUT2 2.3 -SSFC1 2.4 -SSFC2 2.4; -SBT1 =GAB2/1.5 -SBT2 =GAB2/1.8; -SCL 3.4; -SDA 3.4; 4.3 / -PWMR1; 4.3 / PWML1; 4.4 / PWMR2; 4.4 / -PWML2; 4.5 / PWMR3; 4.6 / -PWML3

=F Interconexão microcontrolador ESP32

Controle da parada de emergência | Esquema de engenharia elétrica

## -OPTO1

## -SBUT1

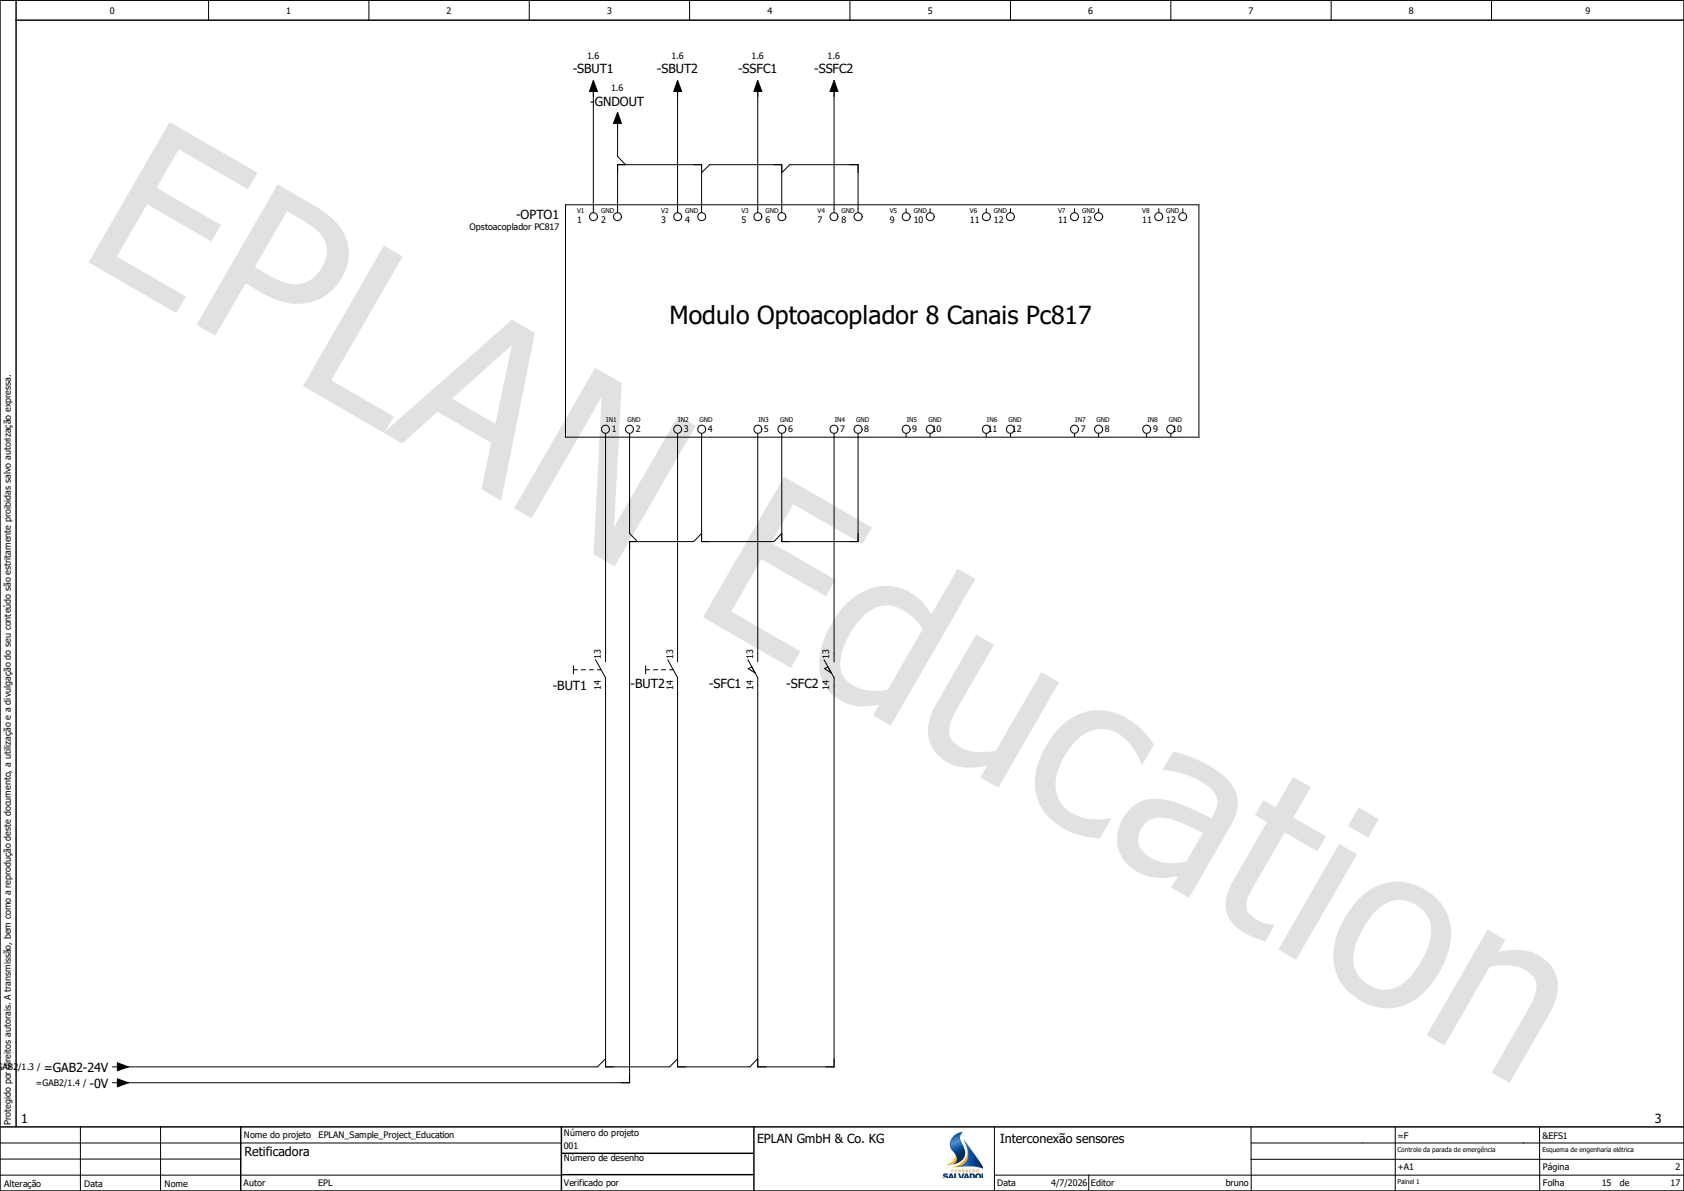
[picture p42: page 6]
=F Interconexão sensores; Autor; EPL Protegido por direitos autorais. A transmissão, bem como a reprodução deste documento, a utilização e a divulgação do seu conteúdo são estritamente proibidas salvo autorização expressa.; Opstoacoplador PC817; GND; GND 13; -BUT1 14; -BUT2 14; -SFC1 14; -SFC2 14; -SBUT2; -SSFC1; -SSFC2; -GNDOUT; =GAB2/1.3 / =GAB2-24V =GAB2/1.4 / -0V

Modulo Optoacoplador 8 Canais Pc817

# Módulo I2C

## -OPTO2

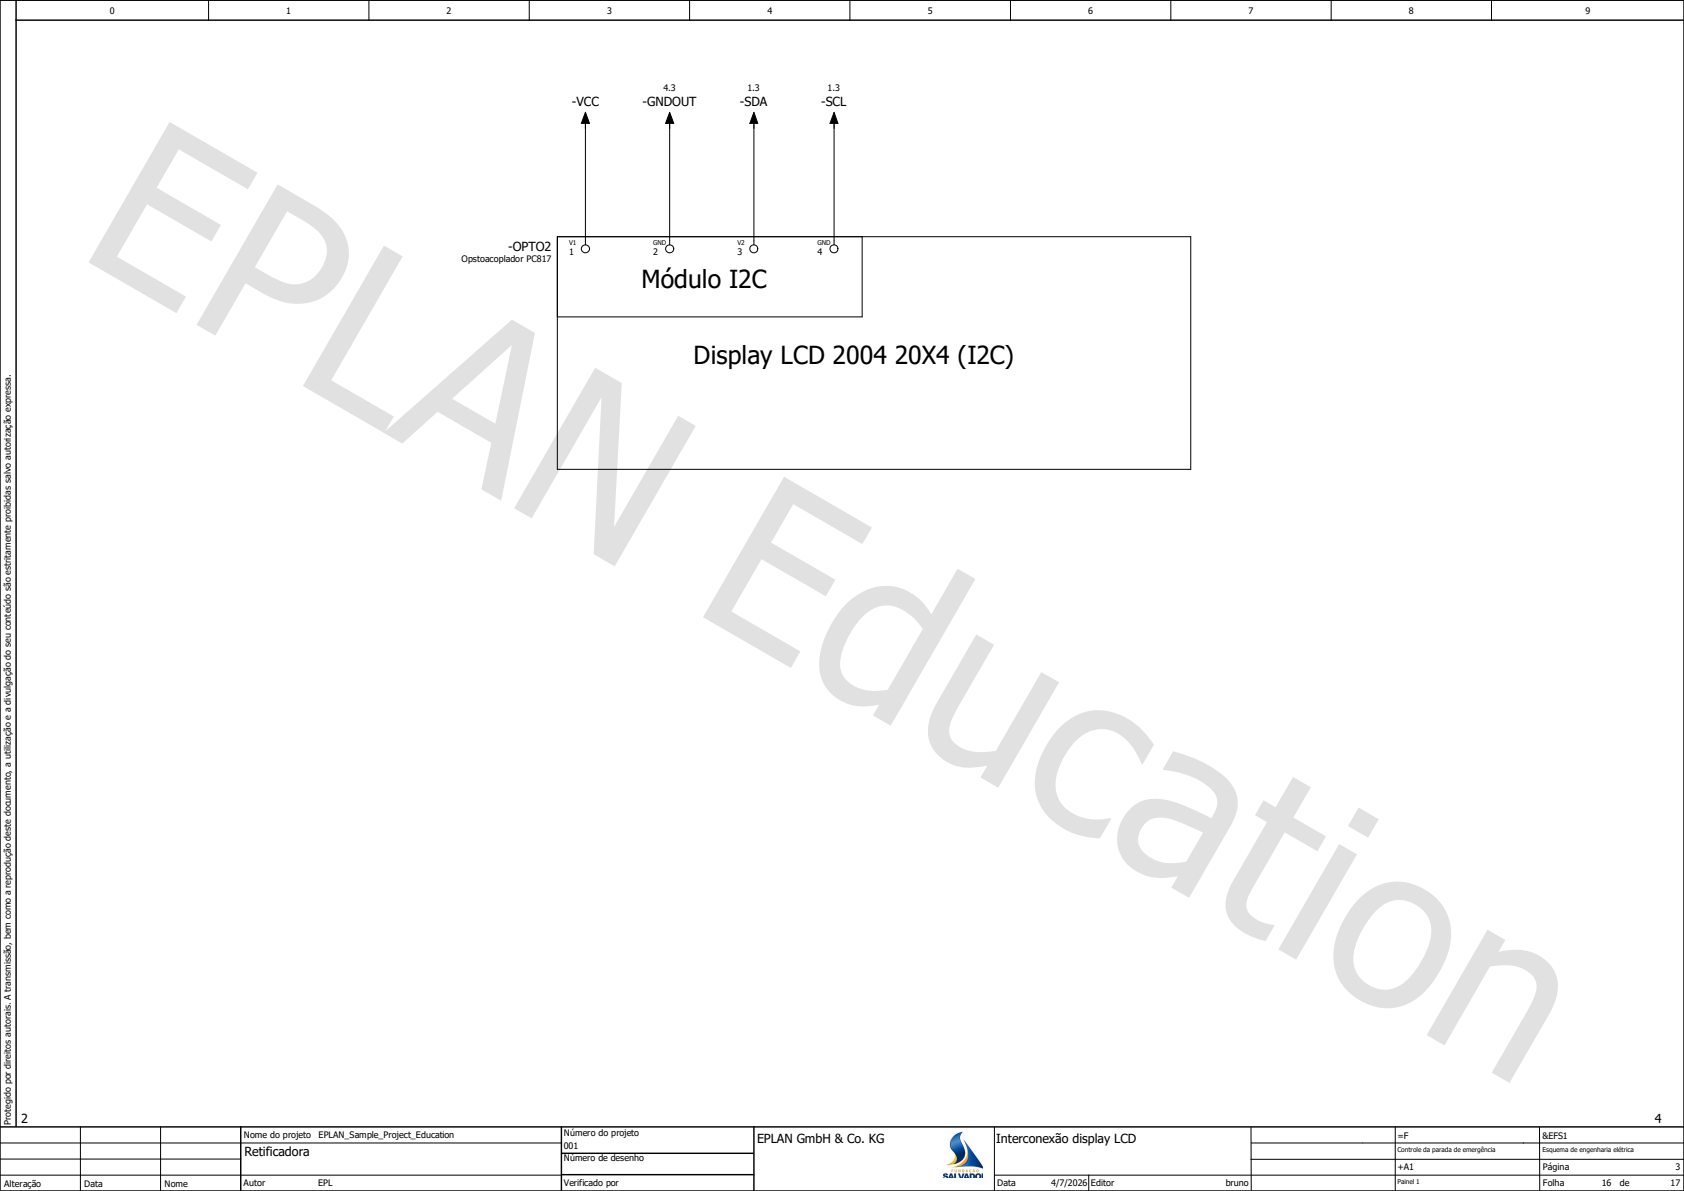
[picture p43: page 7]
Autor; EPL Protegido por direitos autorais. A transmissão, bem como a reprodução deste documento, a utilização e a divulgação do seu conteúdo são estritamente proibidas salvo autorização expressa.; Display LCD 2004 20X4 (I2C); Opstoacoplador PC817; GND; -VCC; -GNDOUT; -SDA; -SCL

=F Interconexão display LCD
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

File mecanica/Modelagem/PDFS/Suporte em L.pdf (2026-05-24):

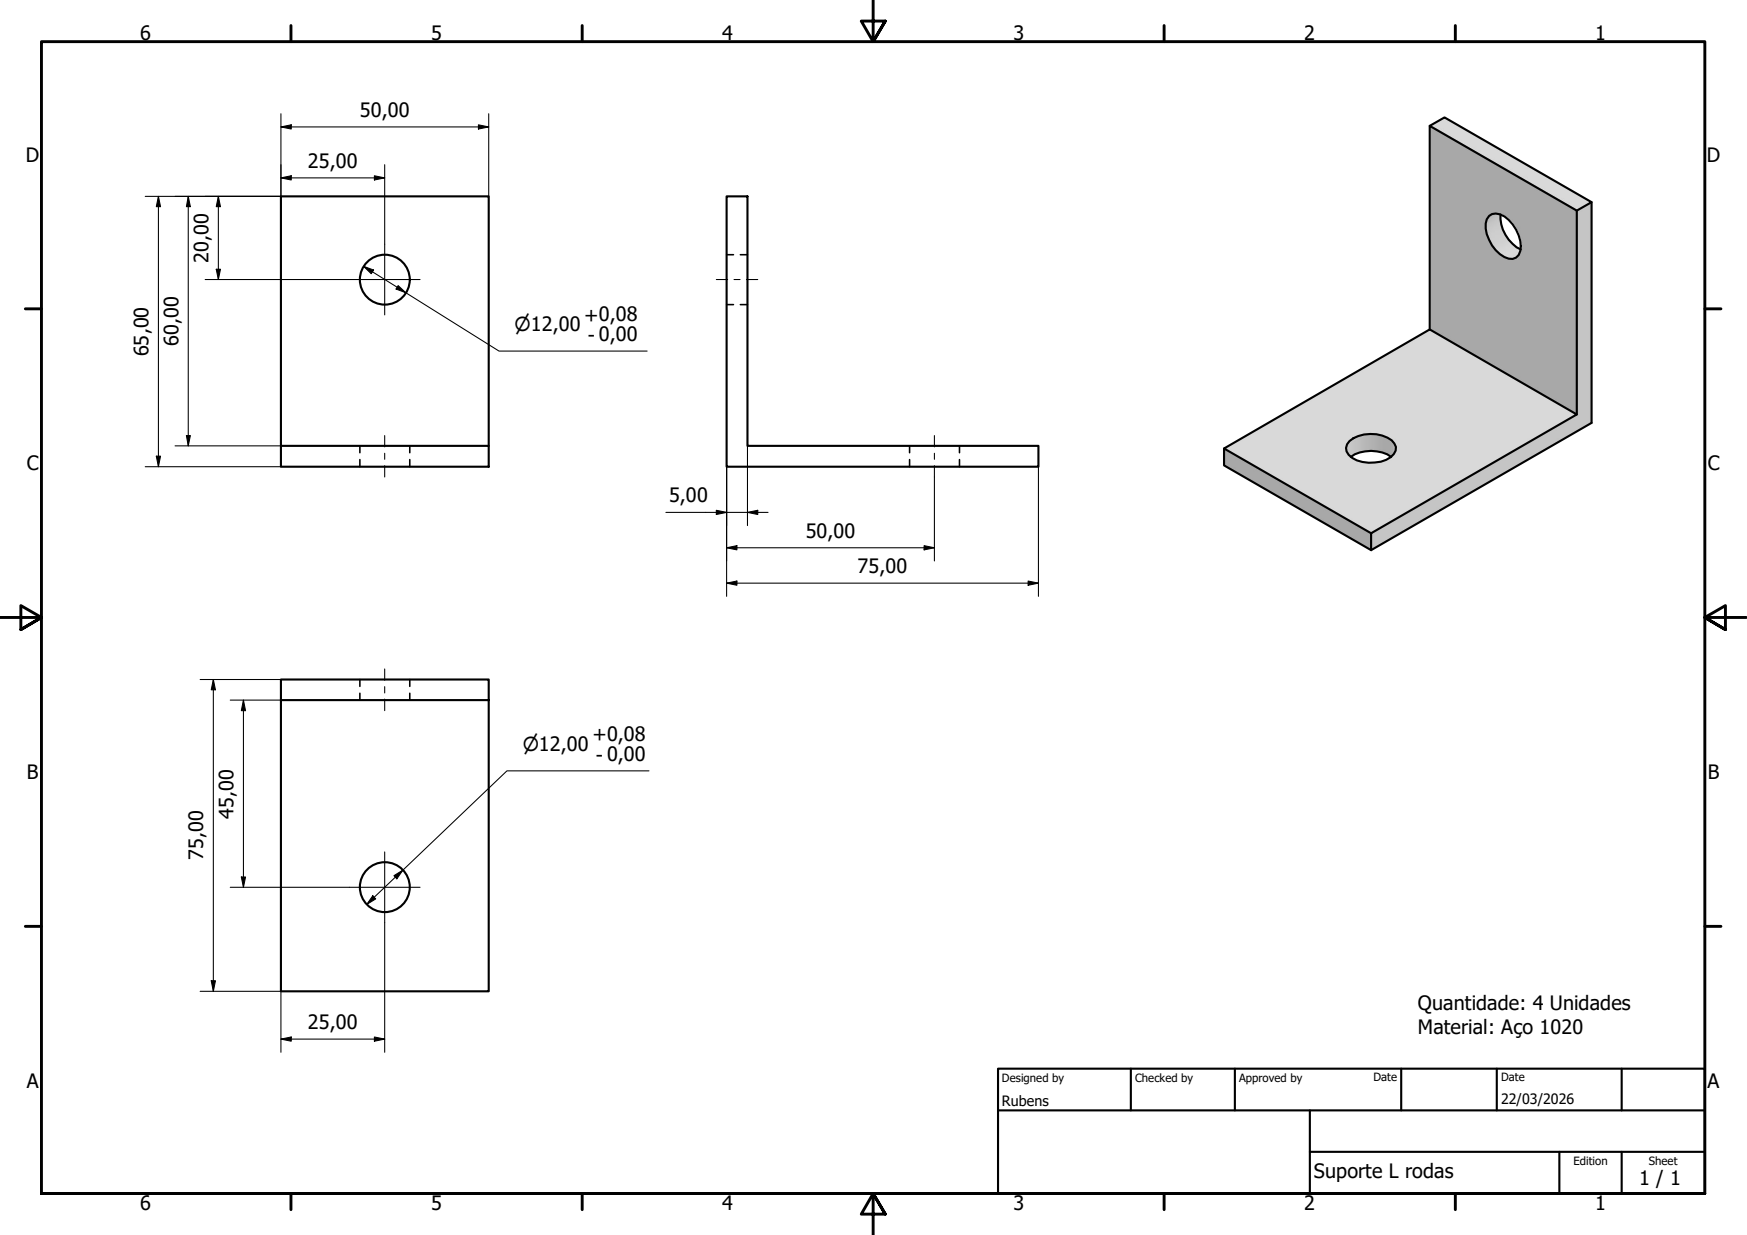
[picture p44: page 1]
Suporte L rodas; Designed by; Checked by; Approved by; Date; Quantidade: 4 Unidades Material: Aço 1020

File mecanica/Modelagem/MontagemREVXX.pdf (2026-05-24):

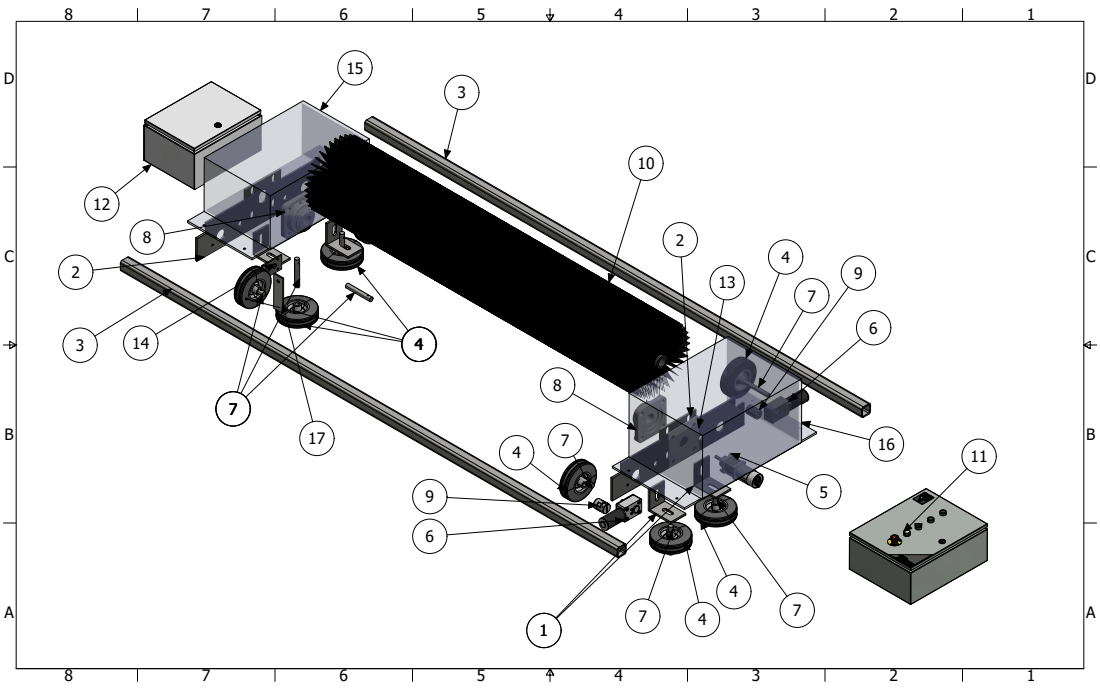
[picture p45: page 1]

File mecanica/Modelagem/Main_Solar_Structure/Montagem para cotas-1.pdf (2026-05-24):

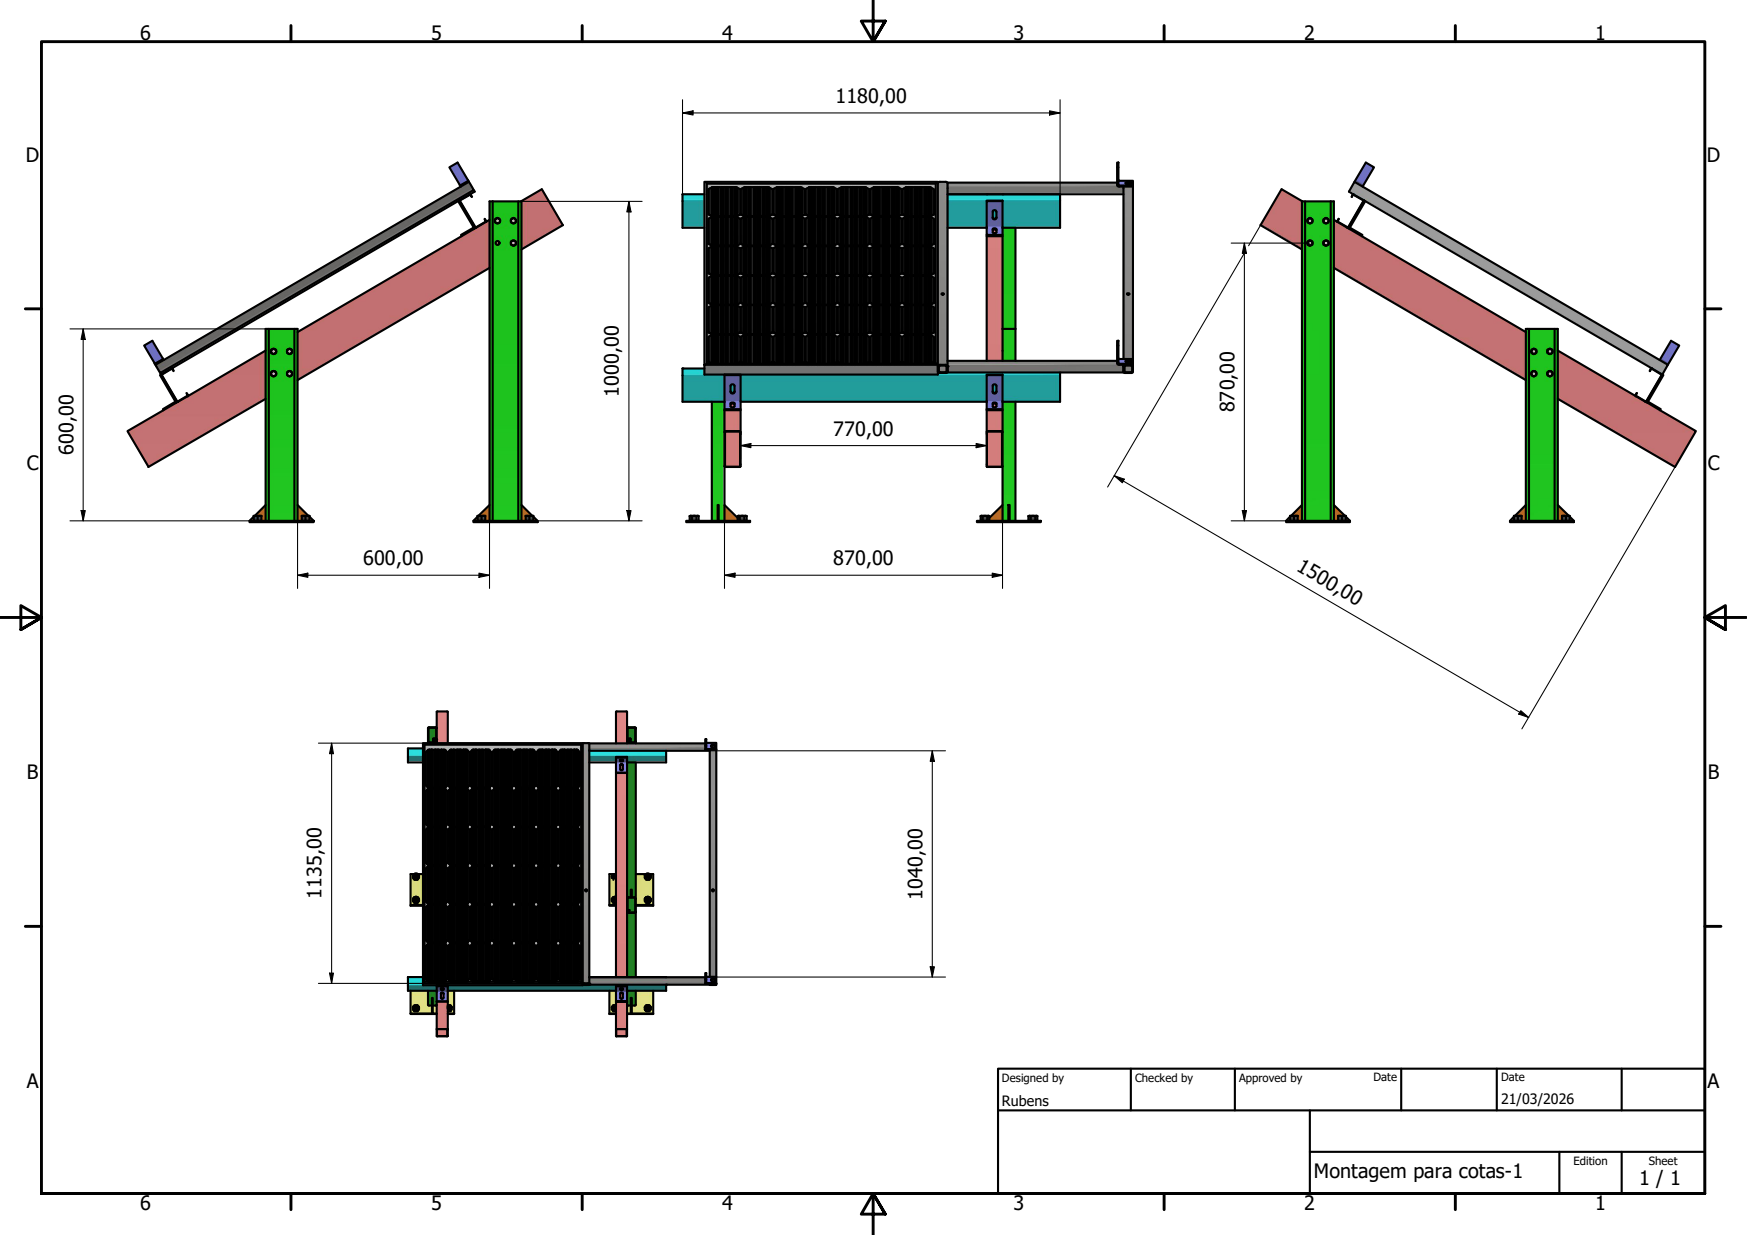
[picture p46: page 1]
Designed by; Checked by; Approved by; Date

Montagem para cotas-1

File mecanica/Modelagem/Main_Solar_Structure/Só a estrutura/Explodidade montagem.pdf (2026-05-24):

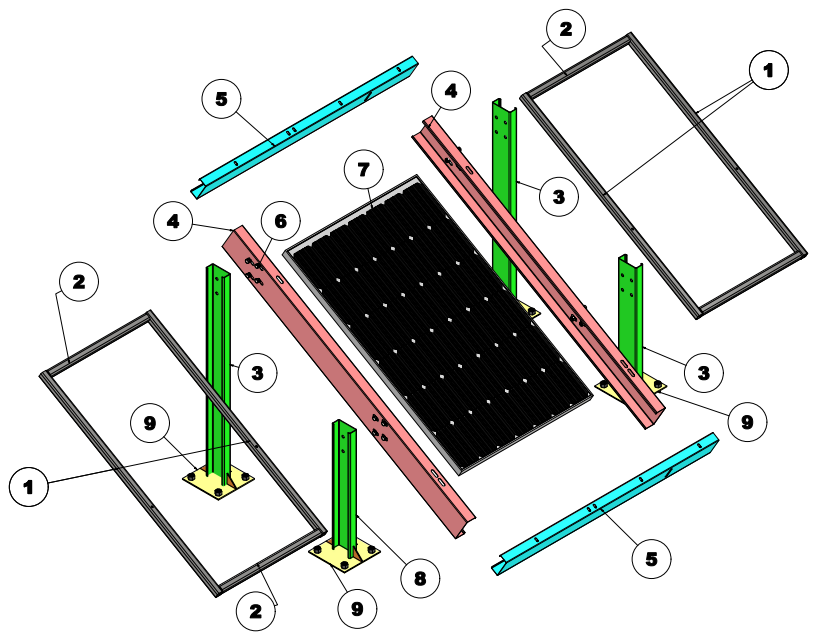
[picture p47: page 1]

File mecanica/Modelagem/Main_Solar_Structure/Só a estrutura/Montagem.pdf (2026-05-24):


I T E M | Q TY | P A RT N U M B E R | D E S C R I P T I O N
1 | 2 | P e r f il U _ 6 0 0 m m | P e r f il U -1 0 0 x 4 0
2 | 2 | P e r f il U _ 1 5 0 0 m m | P e r f il U -1 3 0 x 5 0
3 | 2 | P e r f il U _ 1 1 8 0 m m | P e r f il U -1 0 0 x 4 0
4 | 2 | P e r f il U -1 0 0 0 m m | P e r f il U -1 0 0 x 4 0

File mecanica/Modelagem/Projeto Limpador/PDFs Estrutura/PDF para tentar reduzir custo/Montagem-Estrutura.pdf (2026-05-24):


LISTA DE PEÇAS

ITEM | QTDE | NÚMERO DA PEÇA
1 | 1 | Coluna Lateral
2 | 4 | Suporte-Fixador
3 | 2 | Perfil U - 2780
4 | 4 | Tubo Quadrado- 30x30x3 - 2280
5 | 4 | Tubo Quadrado - 30 x 30 x 3 -550

6 | 2 | Coluna Maior
7 | 4 | Limitador-carrinho
8 | 2 | Coluna menor

Projetado por Rubens | Verificado por | Aprovado por Data | Data 09/11/2025


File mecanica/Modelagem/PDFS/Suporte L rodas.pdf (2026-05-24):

Suporte L rodas; Designed by; Checked by; Approved by; Date

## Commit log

2026-05-24 Adicionando modelagem completa do Inventor.
    [22874-100-g-a.ipt, 22874-100-g-a_MIR.ipt, Base.0001.ipt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]
2026-06-07 Rename Protótipo de sistema automatizado de limpeza de placas solares com controle web e alimentação autônoma.pdf to Artigo_Limpeza_Paineis_Fotovoltaicos.pdf
